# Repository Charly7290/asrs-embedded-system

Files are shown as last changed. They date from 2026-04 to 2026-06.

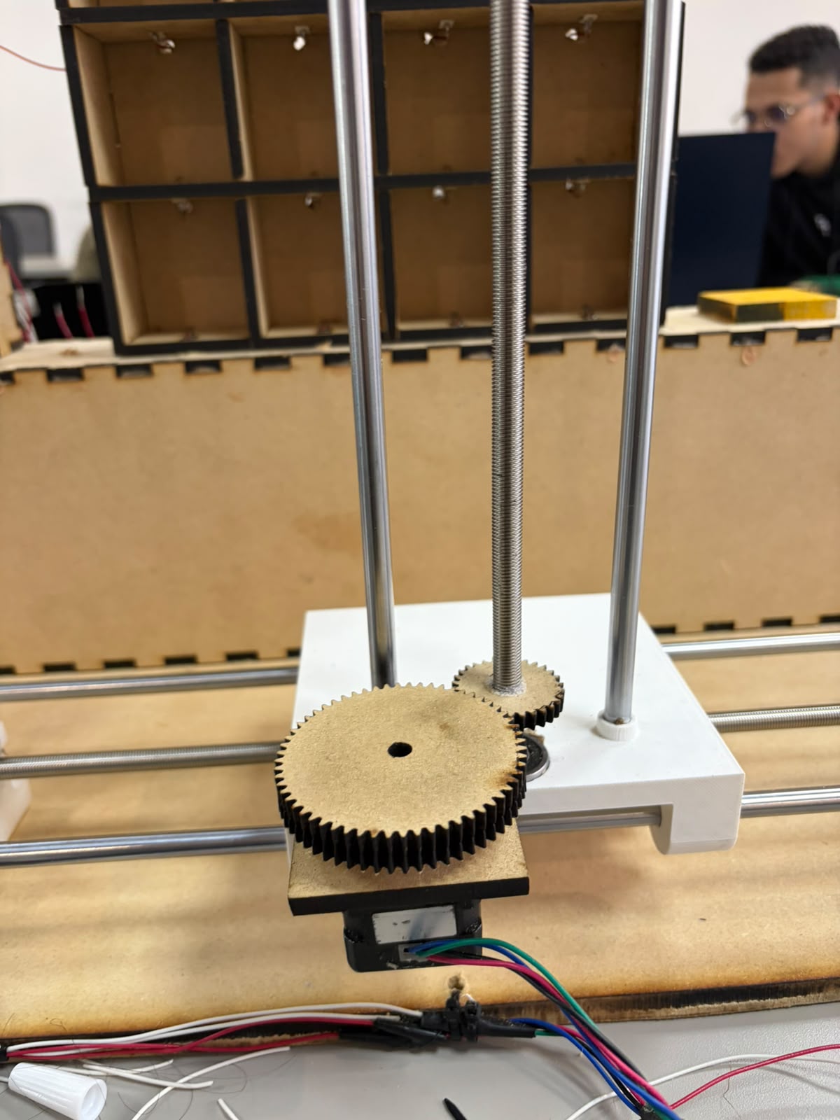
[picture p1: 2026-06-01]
hardware/photos/yshaft-transmission-system.jpeg

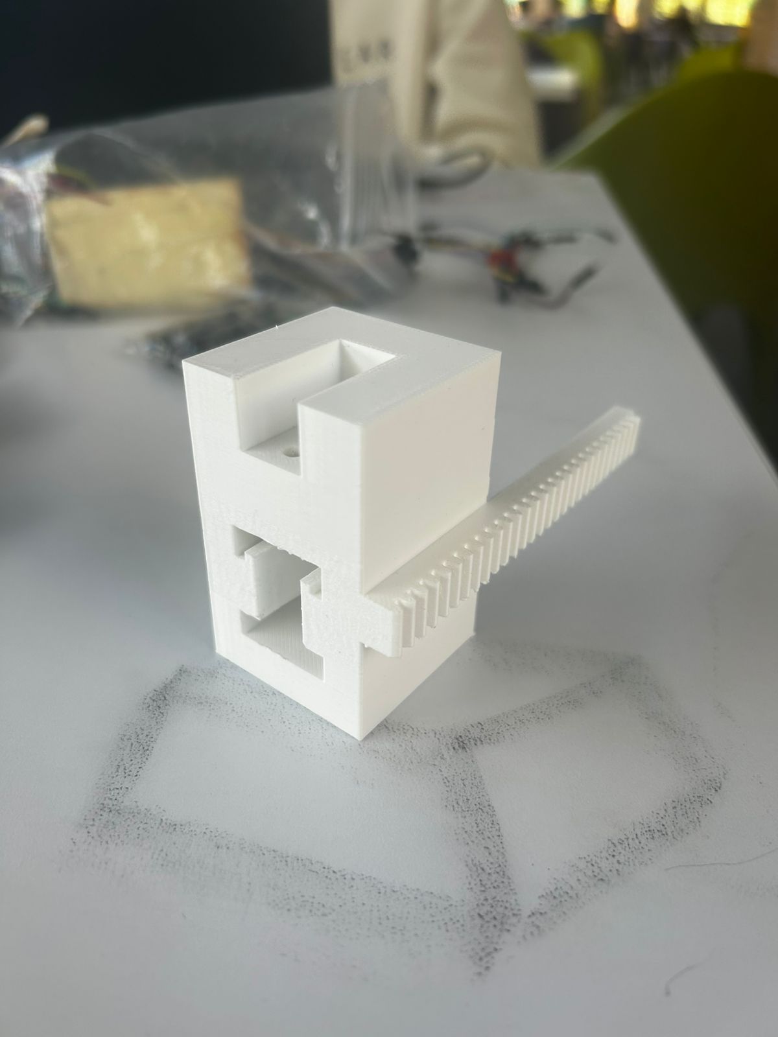
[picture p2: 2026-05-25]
hardware/photos/3dprint-end-effector.jpeg

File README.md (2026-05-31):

# AS/RS Embedded System

Prototipo de sistema embebido para un **Sistema Automatizado de Almacenamiento y Recuperación (AS/RS – Automated Storage and Retrieval System)** desarrollado como proyecto del curso de Sistemas Embebidos en la Universidad EIA.

> **Estado del proyecto:** Finalizado

---

## Estructura del repositorio

```
asrs-embedded/
├── docs/                    # Documentación del proyecto / Entregas
│   ├── firmware-design/     # Embedded Firmware Design Document
│   ├── test-cases/evidence/ # Evidencia de pruebas ejecutadas
│   └── images/              # Diagramas, fotos, capturas
├── firmware/                # Proyecto PlatformIO
│   ├── src/                 # Código fuente
│   │   ├── hal/             # Abstracción de hardware
│   │   ├── drivers/         # Drivers (stepper, l298n, mcp23017)
│   │   ├── services/        # Lógica de negocio (motion, inventory, logger)
│   │   └── app/             # Máquina de estados principal
│   ├── include/             # Headers globales (config, error codes)
│   ├── lib/                 # Librerías externas
│   └── test/                # Unit tests
├── hardware/                # Diseño electrónico
│   ├── schematic/           # Proyecto KiCad
│   ├── pcb/                 # Diseño de PCB 
│   ├── enclosure/           # Diseño CAD de la carcasa
│   └── photos/              # Fotos del ensamblaje
└── gui/                     # Interfaz gráfica de usuario
```

---

## Cómo compilar

### Requisitos

- [VS Code](https://code.visualstudio.com/) con la extensión [PlatformIO](https://platformio.org/)
- Cable USB para ESP32

### Pasos

```bash
git clone https://github.com/<usuario>/asrs-embedded.git
cd asrs-embedded
# Abrir con VS Code — PlatformIO detecta el proyecto automáticamente
# Compilar: Ctrl+Alt+B o botón ✓ en la barra de PlatformIO
# Subir al ESP32: Ctrl+Alt+U o botón →
# Monitor serial: Ctrl+Alt+S o botón 🔌
```

---

## Introducción

Los sistemas automatizados de almacenamiento y recuperación (AS/RS) son ampliamente utilizados en entornos industriales y logísticos para mejorar la eficiencia en la gestión de inventarios, reducir errores humanos y optimizar el uso del espacio de almacenamiento. Estos sistemas permiten almacenar, clasificar y recuperar productos mediante mecanismos automatizados controlados por sistemas electrónicos y de software.

En este proyecto se propone el diseño e implementación de un sistema embebido capaz de controlar un prototipo compacto de AS/RS, implementando sensado, actuación, protocolos de comunicación y una interfaz de usuario para gestionar las operaciones del sistema.

El sistema permitirá a un operario almacenar, recuperar e intercambiar productos dentro de diferentes compartimentos, manteniendo registro del estado del sistema y validando las operaciones mediante sensores y mediciones físicas.

El desarrollo del sistema seguirá buenas prácticas de ingeniería en hardware y firmware, incluyendo diseño arquitectónico, manejo de errores, trazabilidad de requisitos, validación mediante pruebas y documentación técnica formal.

---

## Descripción del Problema

En muchos entornos de almacenamiento de pequeña y mediana escala, como laboratorios, bodegas técnicas o entornos educativos, la gestión de inventarios se realiza de forma manual.

Este proceso presenta diversos problemas:

- Pérdida de tiempo en la búsqueda de productos.
- Errores humanos al ubicar o retirar elementos.
- Falta de control sobre la presencia o ausencia de productos en los compartimentos.
- Dificultad para mantener registros confiables del estado del sistema.

Los sistemas comerciales de AS/RS solucionan estos problemas, pero suelen tener alto costo y complejidad, lo que limita su implementación en entornos educativos o prototipos experimentales.

Por esta razón, este proyecto propone el desarrollo de un prototipo de sistema automatizado de almacenamiento y recuperación controlado por un sistema embebido, capaz de gestionar de forma automática el almacenamiento y recuperación de productos dentro de una estructura de compartimentos.

---

## Alcance del Proyecto

El proyecto contempla el desarrollo de un prototipo funcional de un sistema AS/RS compacto controlado por un sistema embebido, capaz de gestionar el almacenamiento y recuperación de productos.

El sistema incluirá los siguientes componentes:

- Un **mecanismo de posicionamiento** capaz de acceder a diferentes compartimentos de almacenamiento.
- **Sensores de presencia** para determinar si un compartimento contiene un producto.
- **Celdas de carga** para medir el peso del producto almacenado.
- **Actuadores controlados electrónicamente** para el movimiento del sistema.
- **Protocolos de comunicación** entre los módulos electrónicos (UART e I2C).
- Un **sistema de logging** que registre eventos, estados y errores del sistema.
- Una **interfaz gráfica de usuario (GUI)** que permita configurar parámetros, visualizar el estado del sistema y consultar errores o eventos relevantes.

La implementación física incluirá tarjeta electrónica ensamblada, fuente de alimentación externa, estructura mecánica funcional y carcasa de protección.

El proyecto se limita al desarrollo de un prototipo demostrativo a escala, orientado a validar la arquitectura y funcionamiento del sistema embebido.

---

## Objetivos

### Objetivo General

Diseñar e implementar un sistema embebido para el control de un sistema automatizado de almacenamiento y recuperación (AS/RS) que permita gestionar operaciones de almacenamiento, recuperación e intercambio de productos mediante sensores, actuadores y una interfaz de usuario.

### Objetivos Específicos

1. Diseñar la arquitectura de hardware y firmware del sistema embebido.
2. Implementar mecanismos de sensado de presencia y medición de peso en los compartimentos.
3. Desarrollar el control de actuadores para el posicionamiento del sistema.
4. Implementar un sistema de logging estructurado que registre eventos, estados y errores.
5. Integrar protocolos de comunicación entre módulos electrónicos (UART e I2C).
6. Diseñar e implementar una interfaz gráfica de usuario (GUI) para interacción con el sistema.
7. Implementar mecanismos robustos de manejo de errores y validación de sensores.
8. Realizar pruebas funcionales del sistema, asegurando la trazabilidad entre requisitos y pruebas.

---

## Equipo de Desarrollo

### Technical Lead — Carlos Daniel Murillo Mena
- Definir la arquitectura general del sistema.
- Aprobar decisiones técnicas del proyecto.
- Garantizar coherencia entre requisitos, diseño e implementación.
- Supervisar la integración y administrar el repositorio.

### Firmware Engineer — Owen Montiel Cardeñas
- Desarrollo de los módulos de firmware.
- Implementación del control de sensores y actuadores.
- Desarrollo del sistema de logging y protocolos de comunicación.
- Documentación del código fuente.

### Hardware Integration Engineer — Mateo Aldana Escobar
- Diseño del esquemático electrónico y PCB.
- Integración de sensores, actuadores y microcontrolador.
- Validación eléctrica del sistema.
- Ensamblaje físico y diseño de la carcasa.

### Verification & Testing Engineer — Michael Cuello Perez
- Definir el plan de pruebas del sistema.
- Construir y mantener la SRTM.
- Validar los requisitos mediante casos de prueba.
- Recolectar evidencia del funcionamiento del sistema.

---

## Entregas

| # | Entregable | Fecha | Estado |
|---|---|---|---|
| 1 | README + roles + problema | 11/03/2026 | ✅ |
| 2 | SRS + plan de testing + SRTM | 27/03/2026 | ✅ |
| 3 | Diagrama de bloques + esquemático + BOM | 17/04/2026 | ✅ |
| 4 | Entrega final + demo | 18–22/05/2026 | ✅ |

---

*Proyecto de Sistemas Embebidos — Universidad EIA — Periodo académico 2026-1*

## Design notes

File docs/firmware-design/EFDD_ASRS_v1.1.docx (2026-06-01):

EMBEDDED FIRMWARE DESIGN DOCUMENT

Sistema Automatizado de Almacenamiento y Recuperación (AS/RS)

Proyecto | AS/RS Embedded System
Curso | Sistemas Embebidos — 2026-1
Institución | Universidad EIA — Escuela de Ingeniería y Ciencias Básicas
Technical Lead | Carlos Daniel Murillo Mena
Firmware Engineer | Owen Montiel Cardeñas
HW Integration Engineer | Mateo Aldana Escobar
V&T Engineer | Michael Cuello Perez
Fecha | 2026-05-25
Versión | 1.2

# Control de versiones

Versión | Fecha | Autor | Cambios
1.0 | 2026-05-25 | Technical Lead | Versión inicial del EFDD.
1.1 | 2026-05-31 | Technical Lead | SRTM actualizada con TC-001 a TC-015 modulares por subsistema. Diagrama de estados rediseñado. Sección 12 actualizada para referenciar esquemático en repositorio.

# 1. Introducción

## 1.1 Descripción del sistema

El AS/RS (Automated Storage and Retrieval System) es un sistema embebido compacto que automatiza el almacenamiento y recuperación de productos en una estructura de 12 celdas organizadas en una matriz de 3 columnas por 4 filas. Un carro motorizado se desplaza en dos ejes — horizontal (X) y vertical (Y) — mediante motores NEMA17 controlados por módulos L298N, posicionándose en cualquiera de las 12 celdas para depositar o retirar productos a través de un extractor tipo servo.

El sistema es controlado por un ESP32-WROOM-32 que ejecuta firmware sobre FreeRTOS. Cada celda cuenta con un microswitch de presencia leído a través de un expansor I2C MCP23017. El peso del producto se mide mediante una celda de carga TAL221 con circuito de acondicionamiento analógico discreto. Una aplicación de escritorio en Python/tkinter se comunica con el ESP32 por UART para enviar comandos (STORE, RETRIEVE, SWAP) y visualizar el estado del inventario en tiempo real.

El proyecto fue desarrollado como prototipo educativo en el curso de Sistemas Embebidos de la Universidad EIA, periodo 2026-1, aplicando prácticas de ingeniería industrial: arquitectura en capas, máquina de estados, logging estructurado, trazabilidad de requisitos y verificación mediante casos de prueba.

## 1.2 Alcance del documento

Este documento especifica la arquitectura de hardware y firmware del sistema embebido. Define las decisiones de diseño, la estructura del firmware, los mecanismos de comunicación, la estrategia de logging, el manejo de errores y la trazabilidad con los requisitos del SRS.

El documento es el artefacto técnico central del proyecto y sirve como referencia para el desarrollo, la integración y la verificación del sistema.

# 2. Diagrama de bloques del sistema embebido

La figura 1 muestra la arquitectura de bloques del sistema embebido, incluyendo el microcontrolador central, los subsistemas de actuación y sensado, los bloques de comunicación y el circuito de seguridad.

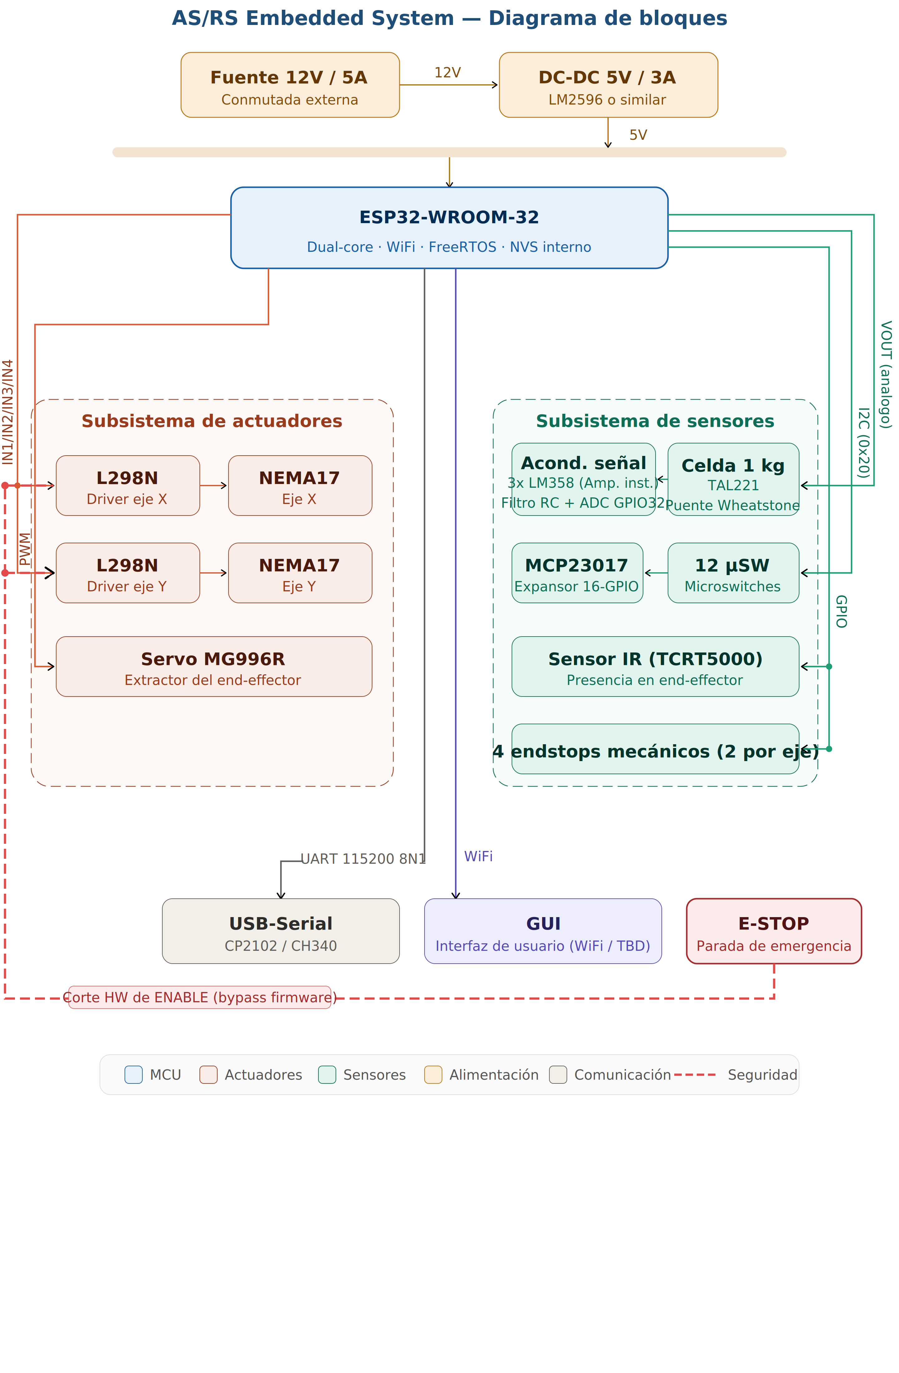
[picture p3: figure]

Figura 1. Diagrama de bloques del sistema AS/RS.

# 3. Arquitectura de firmware

## 3.1 Modelo arquitectónico

El firmware se organiza en cuatro capas horizontales. Cada capa solo interactúa con la capa inmediatamente inferior, garantizando bajo acoplamiento y alta cohesión. La implementación se realiza en C con módulos funcionales (archivos .c/.h), compilados con PlatformIO sobre el framework Arduino/ESP-IDF.

Capa | Módulos | Responsabilidad
Application | system.c — SystemController | Máquina de estados principal. Coordina todas las operaciones del sistema.
Services | motion.c, inventory.c, weight.c | Lógica de negocio: secuencias de movimiento, gestión de inventario, medición de peso.
Drivers | stepper.c, servo.c, mcp23017.c, load_cell.c, endstop.c, ir_sensor.c | Abstracción de hardware. Encapsula el acceso directo a periféricos.
HAL | gpio.c, i2c.c, adc.c, uart.c | Wrappers sobre ESP-IDF. Aíslan el resto del firmware de la API de bajo nivel.
Cross-cutting | logger.c, error_codes.h | Usados por todas las capas. Logger para UART, códigos de error estructurados.

## 3.2 Tareas FreeRTOS

El firmware ejecuta cinco tareas concurrentes sobre FreeRTOS. La comunicación entre tareas se realiza mediante colas (QueueHandle_t) y semáforos (SemaphoreHandle_t).

Tarea | Prioridad | Stack (words) | Responsabilidad
Task_SystemControl | 5 (más alta) | 4096 | Máquina de estados. Toma decisiones de sistema y despacha comandos.
Task_MotionControl | 4 | 4096 | Ejecuta secuencias de movimiento de steppers y servo.
Task_SensorRead | 3 | 2048 | Lee celda de carga, microswitches (MCP23017), sensor IR y endstops.
Task_Logger | 2 | 2048 | Consume la cola de log y envía por UART. Nunca bloquea otras tareas.
Task_GUIComm | 2 | 2048 | Recibe comandos de la GUI por UART y envía actualizaciones de estado.

# 4. Justificación de arquitectura

## 4.1 Lenguaje y toolchain

Se utiliza C con PlatformIO sobre Arduino/ESP-IDF. La elección de C sobre C++ se justifica por la disponibilidad inmediata de ejemplos y librerías para ESP32 en C, la facilidad de depuración y la reducción del tiempo de desarrollo dado el cronograma del proyecto. PlatformIO permite integración con Unity para pruebas unitarias.

## 4.2 Arquitectura en capas

La separación en capas garantiza que un cambio de hardware (por ejemplo, reemplazar el L298N por un DRV8825 en el futuro) solo requiere modificar la capa de drivers, sin afectar la lógica de servicios ni la máquina de estados. Esto reduce el riesgo de regresiones durante la integración.

## 4.3 Uso de FreeRTOS

FreeRTOS permite que el logging y la comunicación con la GUI operen de forma asíncrona sin bloquear el control de movimiento. La tarea de motion tiene prioridad más alta que el logger, garantizando que los tiempos de ciclo no se degraden por operaciones de I/O.

## 4.4 Módulos funcionales en lugar de POO

Se descartó POO con clases C++ para reducir el tiempo de diseño inicial. Los módulos funcionales con estructuras (struct) proveen encapsulamiento suficiente sin el overhead de vtables ni la complejidad de gestión de objetos en embedded. Cada módulo expone una API pública en su .h y mantiene su estado interno en variables estáticas del .c.

# 5. Diagrama de estados del firmware

La figura 2 muestra la máquina de estados del firmware con los 7 estados del sistema y todas sus transiciones.

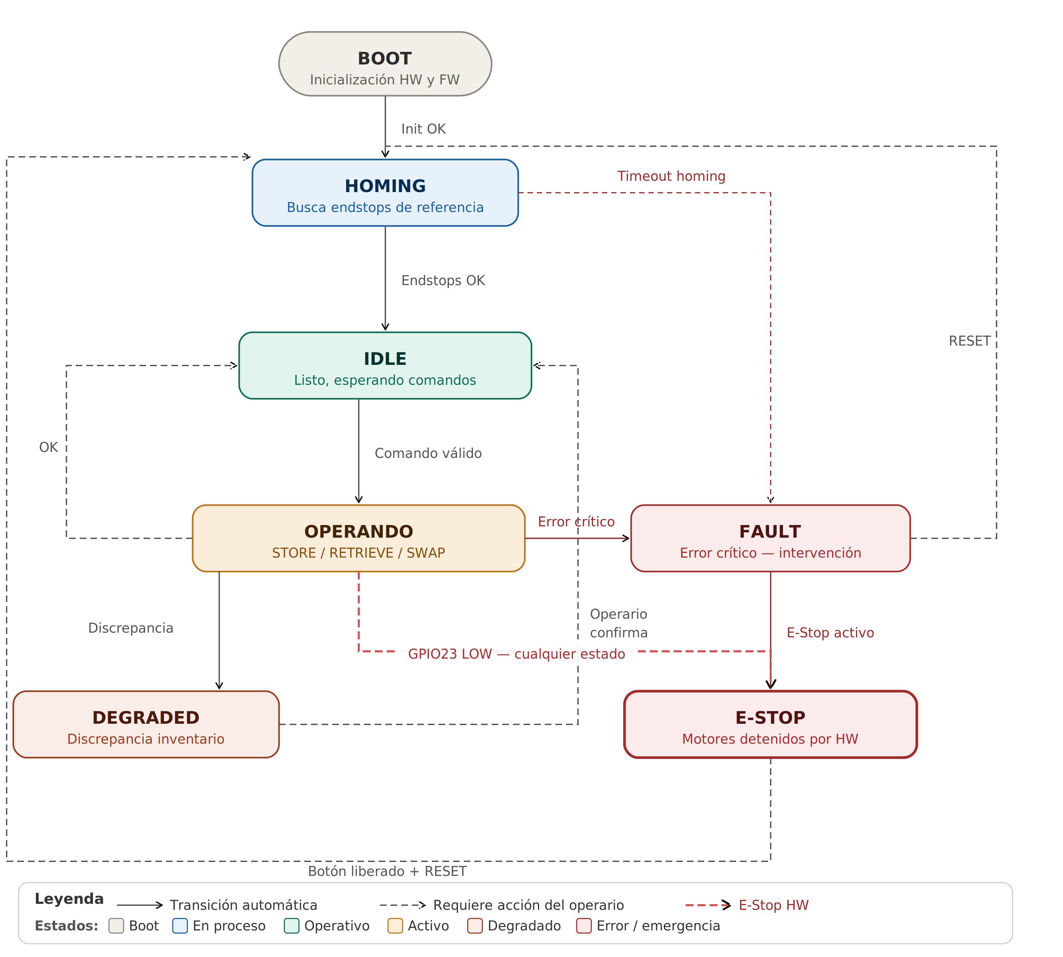
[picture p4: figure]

Figura 2. Diagrama de estados del firmware AS/RS.

## 5.1 Estados del sistema

Estado | Descripción
BOOT | Inicialización de hardware, HAL, drivers y FreeRTOS. Imprime versión de firmware en UART.
HOMING | Secuencia de homing: mueve ambos ejes hasta los endstops de referencia. Duración ≤30 s.
IDLE | Sistema listo. Espera comandos de la GUI. Actualiza estado de inventario periódicamente.
OPERANDO | Ejecutando una operación STORE, RETRIEVE o SWAP. No acepta nuevos comandos hasta completar.
DEGRADED | Discrepancia entre NVS y microswitches detectada. Sistema opera pero requiere confirmación del operario.
FAULT | Error crítico (sensor fuera de rango, timeout de movimiento). Requiere intervención del operario.
E-STOP | Botón de emergencia activo. Motores detenidos por hardware. Requiere reset y nuevo homing.

## 5.2 Transiciones

Desde | Hacia | Condición
BOOT | HOMING | Inicialización completa sin errores.
HOMING | IDLE | Ambos endstops de home alcanzados dentro del tiempo límite.
HOMING | FAULT | Timeout de homing (>30 s) o endstop no detectado.
IDLE | OPERANDO | Comando válido recibido de la GUI (STORE, RETRIEVE o SWAP).
OPERANDO | IDLE | Operación completada exitosamente.
OPERANDO | FAULT | ERR_WEIGHT_OUT_OF_RANGE, ERR_SENSOR_TIMEOUT, ERR_MOTION_TIMEOUT.
IDLE / OPERANDO | DEGRADED | Discrepancia entre NVS y estado real de microswitches en reconciliación.
DEGRADED | IDLE | Operario confirma reconciliación desde la GUI.
Cualquier estado | E-STOP | GPIO 23 cae a LOW (botón de emergencia presionado).
E-STOP | HOMING | Botón liberado + comando RESET desde GUI.
FAULT | HOMING | Comando RESET desde GUI.

# 6. Estrategia de manejo de errores

## 6.1 Códigos de error

Todos los errores siguen el patrón ERR_MÓDULO_CONDICIÓN. Se definen en error_codes.h como enumeraciones.

Código | Severidad | Acción del sistema
ERR_WEIGHT_OUT_OF_RANGE | ERROR | Detener operación, transición a FAULT, log ERROR.
ERR_WEIGHT_TIMEOUT | ERROR | Detener operación, transición a FAULT, log ERROR.
ERR_MOTION_TIMEOUT | ERROR | Deshabilitar motor, transición a FAULT, log ERROR.
ERR_SENSOR_TIMEOUT | ERROR | Transición a FAULT, log ERROR.
ERR_INVENTORY_DISCREPANCY | WARN | Transición a DEGRADED, log WARN, notificar GUI.
ERR_CELL_OCCUPIED | WARN | Rechazar operación STORE, log WARN.
ERR_CELL_EMPTY | WARN | Rechazar operación RETRIEVE, log WARN.
ERR_ESTOP_ACTIVE | ERROR | Transición a E-STOP, deshabilitar motores, log ERROR.
ERR_NOT_READY | WARN | Rechazar comando, log WARN.

## 6.2 Política de manejo

- Cada función de driver retorna un código de error (int). El valor 0 indica éxito.
- Las funciones de servicio verifican el retorno del driver y propagan el error hacia la capa superior.
- La tarea Task_SystemControl evalúa el error y decide la transición de estado correspondiente.
- Ningún error se ignora silenciosamente — todo error queda registrado en el log con nivel y código.
- Los errores WARN no detienen la operación en curso salvo indicación explícita.
- Los errores ERROR siempre detienen la operación y transicionan al estado FAULT o E-STOP.

# 7. Estructura de directorios y flujo de trabajo

## 7.1 Estructura del repositorio

asrs-embedded/

├── docs/ # Documentación del proyecto

│ ├── firmware-design/ # Embedded Firmware Design Document

│ ├── test-cases/

│ │ └── evidence/ # Evidencia de pruebas ejecutadas

│ └── images/ # Diagramas, fotos, capturas

├── firmware/ # Proyecto PlatformIO

│ ├── src/ # Código fuente

│ │ ├── hal/ # Abstracción de hardware

│ │ │ ├── gpio.c / gpio.h

│ │ │ ├── i2c.c / i2c.h

│ │ │ ├── adc.c / adc.h

│ │ │ └── uart.c / uart.h

│ │ ├── drivers/ # Drivers periféricos

│ │ │ ├── stepper.c / stepper.h

│ │ │ ├── servo.c / servo.h

│ │ │ ├── mcp23017.c / mcp23017.h

│ │ │ ├── load_cell.c / load_cell.h

│ │ │ ├── endstop.c / endstop.h

│ │ │ └── ir_sensor.c / ir_sensor.h

│ │ ├── services/ # Lógica de negocio

│ │ │ ├── motion.c / motion.h

│ │ │ ├── inventory.c / inventory.h

│ │ │ └── weight.c / weight.h

│ │ └── app/ # Máquina de estados principal

│ │ ├── system.c / system.h

│ │ └── gui_comm.c / gui_comm.h

│ ├── include/ # Headers globales (config, error_codes.h)

│ ├── lib/ # Librerías externas

│ ├── test/ # Unit tests Unity

│ └── platformio.ini

├── hardware/ # Diseño electrónico

│ ├── schematic/ # Proyecto KiCad (.kicad_sch)

│ ├── pcb/ # Imágenes PCB

│ ├── enclosure/ # Diseño CAD de la carcasa

│ └── photos/ # Fotos del ensamblaje

├── gui/ # App de escritorio Python/tkinter

│ ├── main.py

│ └── requirements.txt

└── README.md

## 7.2 Flujo de trabajo del repositorio

- Rama principal: main — solo código verificado y probado.
- Rama de desarrollo: develop — integración continua de features.
- Ramas de feature: feature/nombre — una por módulo o funcionalidad.
- Pull Request obligatorio para fusionar a develop. Revisado por el Technical Lead.
- Commits siguen convención: feat:, fix:, docs:, test:, refactor:.
- Cada entregable se etiqueta con tag semántico: v1.0, v1.1, etc.

# 8. Estrategia de logging

## 8.1 Formato de mensaje

Todos los mensajes de log siguen el formato estándar:

[timestamp_ms][LEVEL][MODULE][CODE] mensaje

Ejemplo: [001234][ERROR][WEIGHT][ERR_WEIGHT_OUT_OF_RANGE] peso=1050g > maximo=1000g

Ejemplo: [000012][INFO ][BOOT ][0] firmware=v1.0.0 commit=a3f9c12

Ejemplo: [005678][WARN ][INVEN ][ERR_INVENTORY_DISCREPANCY] celda=B2 esperado=OCUPADO actual=VACIO

## 8.2 Niveles de severidad

Nivel | Uso
INFO | Eventos normales del sistema: inicio, finalización de operaciones, cambios de estado.
WARN | Condiciones anómalas no críticas: discrepancias de inventario, celdas ocupadas al intentar STORE.
ERROR | Errores críticos que detienen la operación: sensor timeout, weight out of range, E-Stop activo.

## 8.3 Implementación

- El módulo logger.c mantiene una cola FreeRTOS de 32 entradas de tipo log_entry_t.
- Cualquier módulo puede llamar log_write(level, module, code, message) de forma thread-safe.
- Task_Logger consume la cola y envía por UART 115200 bps 8N1 sin bloquear otras tareas.
- El timestamp se obtiene de xTaskGetTickCount() convertido a ms.
- Al boot, el firmware imprime la línea INFO BOOT con versión semántica y hash del commit.

# 9. Gestión de comunicaciones

## 9.1 UART — Protocolo estándar #1

Parámetro | Valor
Velocidad | 115200 bps
Formato | 8N1 (8 bits datos, sin paridad, 1 bit de parada)
Hardware | USB-Serial CP2102 integrado en ESP32 DevKit V1
Pines | GPIO 1 (TX0) y GPIO 3 (RX0)
Usos | Logging de eventos (Task_Logger) y comunicación bidireccional con GUI (Task_GUIComm)
Justificación | Canal único para logging y GUI simplifica el hardware y reduce el número de puertos serie requeridos.

Protocolo GUI — comandos y respuestas

La GUI envía comandos ASCII terminados en \n. El ESP32 responde con JSON.

Comando STORE: STORE:A1\n

Comando RETRIEVE: RETRIEVE:B3\n

Comando SWAP: SWAP:A1:C4\n

Comando RESET: RESET\n

Respuesta OK: {"status":"OK","op":"STORE","celda":"A1","peso":245.3}

Respuesta ERR: {"status":"ERROR","code":"ERR_CELL_OCCUPIED","celda":"A1"}

Evento estado: {"event":"STATE","state":"IDLE","inventory":{"A1":245,"B3":0,...}}

## 9.2 I2C — Protocolo estándar #2

Parámetro | Valor
Velocidad | 100 kHz (modo estándar)
Pines | GPIO 21 (SDA) y GPIO 22 (SCL)
Dispositivo | MCP23017 — expansor de 16 GPIO para microswitches
Dirección | 0x20 (A0=A1=A2=GND)
Pull-ups | 4.7 kΩ a 3.3V en SDA y SCL (integrados en módulo breakout)
Interrupción | INTA del MCP23017 → GPIO 4 ESP32. Activa baja. Evita polling continuo.
Justificación | I2C permite leer 12 microswitches con solo 2 pines del ESP32. La interrupción INTA garantiza detección inmediata sin polling.

# 10. Descripción del funcionamiento del sistema

## 10.1 Arranque y homing

Al energizar el sistema, el firmware ejecuta la secuencia de boot: inicializa el HAL, configura los drivers de periféricos, imprime la versión en UART y lanza las tareas FreeRTOS. Inmediatamente entra al estado HOMING, en el que mueve ambos ejes hacia sus endstops de referencia (home). Una vez alcanzados los dos endstops, el sistema registra la posición (0,0) como origen y transiciona a IDLE.

Paralelamente, en HOMING se realiza la reconciliación de inventario: se lee el estado real de los 12 microswitches vía MCP23017 y se compara contra el último estado persistido en NVS. Si hay discrepancias, el sistema entra a DEGRADED e informa al operario por la GUI. Si no hay discrepancias, continúa en IDLE.

## 10.2 Operación STORE

El operario envía el comando STORE:XN desde la GUI, donde X es la columna (A, B o C) y N es la fila (1 a 4). El firmware verifica que la celda destino esté vacía consultando el microswitch correspondiente. Si está ocupada, responde con ERR_CELL_OCCUPIED y permanece en IDLE.

Si la celda está vacía, el sistema transiciona a OPERANDO y ejecuta la secuencia: (1) mueve el carro a la posición de la celda usando los motores stepper, (2) activa el servo para extender el end-effector, (3) lee el peso con la celda de carga y lo valida contra el rango 10–1000 g, (4) retrae el servo, (5) actualiza el NVS con el estado de la celda y el peso medido. Al finalizar, responde a la GUI con OK y el peso registrado, y transiciona a IDLE.

## 10.3 Operación RETRIEVE

El operario envía RETRIEVE:XN. El firmware verifica que la celda tenga producto (microswitch activo y peso en NVS > 5 g). Si está vacía, responde ERR_CELL_EMPTY. Si tiene producto, ejecuta: (1) movimiento a la celda, (2) extensión del servo para recoger el producto, (3) verificación de peso en el end-effector (debe coincidir ±15 g con el peso registrado en NVS), (4) retracción del servo, (5) actualización de NVS marcando la celda como vacía. Responde con OK a la GUI.

## 10.4 Operación SWAP

El operario envía SWAP:X1N1:X2N2. El firmware ejecuta dos operaciones secuenciales usando el end-effector como buffer: primero un RETRIEVE de la celda origen, luego un STORE en la celda destino con el producto recuperado, y finalmente un STORE en la celda origen con el producto que estaba en destino. Si cualquier paso falla, el sistema entra a FAULT con el estado del swap registrado en NVS para posible recuperación.

## 10.5 Detención de emergencia

El botón E-Stop corta directamente los pines ENA y ENB de ambos módulos L298N por hardware, deteniendo los motores en menos de 200 ms sin intervención del firmware. La caída del GPIO 23 (pull-down a GND) genera una interrupción en el ESP32 que transiciona el sistema a E-STOP, registra el evento en el log con nivel ERROR y notifica a la GUI. Los motores permanecen deshabilitados hasta que el operario libere el botón y envíe el comando RESET.

# 11. Descripción de módulos de firmware

## 11.1 Capa HAL

Módulo | Descripción y API principal
gpio.c | Wrapper sobre GPIO de ESP-IDF. Configura pines como entrada/salida y lee/escribe niveles lógicos. gpio_init(), gpio_write(), gpio_read().
i2c.c | Inicializa el bus I2C en GPIO 21/22 a 100 kHz. Provee i2c_write_reg() e i2c_read_reg() para comunicación con MCP23017.
adc.c | Configura ADC1 del ESP32 en GPIO 32 con atenuación 11 dB (rango 0–3.3 V). Provee adc_read_mv() que retorna el valor en mV promediado sobre N muestras.
uart.c | Configura UART0 a 115200 bps 8N1. Provee uart_send_string() y uart_read_line() con timeout. Usado por logger.c y gui_comm.c.

## 11.2 Capa Drivers

Módulo | Descripción y API principal
stepper.c | Controla los módulos L298N para los motores NEMA17. Implementa la secuencia de paso completo y medio paso. stepper_init(), stepper_move_steps(motor, steps, dir), stepper_stop(motor).
servo.c | Genera señal PWM a 50 Hz sobre GPIO 13 para el servo MG996R. servo_init(), servo_set_angle(degrees) con rango 0–180°.
mcp23017.c | Driver I2C para el expansor MCP23017. Configura puertos A y B como entradas con pull-ups. Configura INTA como interrupción. mcp_init(), mcp_read_all() retorna uint16_t con estado de 16 pines.
load_cell.c | Acondicionamiento del ADC para la celda de carga. Aplica tara, calibración y promedio de 16 muestras. load_cell_tare(), load_cell_read_grams() retorna float.
endstop.c | Lectura de los 4 endstops mecánicos con debounce por software. endstop_init(), endstop_triggered(axis, type) retorna bool.
ir_sensor.c | Lectura del sensor TCRT5000 en GPIO 33. ir_sensor_init(), ir_sensor_detected() retorna bool.

## 11.3 Capa Services

Módulo | Descripción y API principal
motion.c | Lógica de movimiento de alto nivel. Calcula los pasos necesarios para llegar a una celda dada la topología 3×4 y el tornillo T8 (paso 8 mm). motion_home(), motion_goto_cell(col, row), motion_get_position().
inventory.c | Gestión del estado del inventario. Lee microswitches, actualiza NVS, reconcilia discrepancias. inventory_init(), inventory_get_cell(col, row), inventory_set_cell(col, row, weight), inventory_reconcile().
weight.c | Validación de peso con lógica de negocio. Llama a load_cell_read_grams(), verifica rango 10–1000 g, genera error si fuera de rango. weight_measure_and_validate() retorna error_t.

## 11.4 Capa Application

Módulo | Descripción y API principal
system.c | Máquina de estados principal. Gestiona las transiciones entre BOOT, HOMING, IDLE, OPERANDO, DEGRADED, FAULT y E-STOP. Despacha operaciones STORE, RETRIEVE y SWAP a los servicios correspondientes. system_init(), system_run() (loop principal de la tarea Task_SystemControl).
gui_comm.c | Protocolo de comunicación con la GUI. Parsea comandos ASCII recibidos por UART (STORE, RETRIEVE, SWAP, RESET) y serializa respuestas en JSON. gui_comm_init(), gui_comm_process_rx(), gui_comm_send_state().

## 11.5 Módulos transversales (Cross-cutting)

Módulo | Descripción y API principal
logger.c | Sistema de logging asíncrono. Mantiene una cola FreeRTOS de 32 entradas. log_write(level, module, code, msg) es thread-safe. Task_Logger consume la cola y envía por UART con formato [ts][LEVEL][MODULE][CODE] msg.
error_codes.h | Define la enumeración error_t con todos los códigos ERR_MÓDULO_CONDICIÓN del sistema. Incluido por todos los módulos. No contiene lógica, solo definiciones.

# 12. Esquemático electrónico

El esquematico electronico completo del sistema se encuentra en el repositorio GitHub del proyecto, en el directorio hardware/schematic/. Se incluyen el archivo fuente KiCad (.kicad_sch) y la exportacion en PDF.

13. Matriz de trazabilidad de requisitos (SRTM)

La SRTM completa se encuentra en el documento SRS_AS-RS_v1.4.docx, sección 5. A continuación se presenta un resumen de la trazabilidad entre los requisitos principales y los módulos de firmware que los implementan.

Req. ID | Requisito | Modulo firmware | Test Case
RF-01 | Homing al boot | motion.c, system.c | TC-001
RF-02 | Posicionamiento eje X | motion.c, stepper.c | TC-002
RF-02 | Posicionamiento eje Y | motion.c, stepper.c | TC-003
RF-10 | Parada de emergencia E-Stop | system.c (ISR GPIO 23) | TC-004
RF-07 | Sensor IR TCRT5000 | ir_sensor.c, inventory.c | TC-005
RF-06 | Medicion de peso AD623 | weight.c, load_cell.c | TC-006
RF-07, RF-09 | MCP23017 + microswitches | mcp23017.c, inventory.c | TC-007
RF-12 | Luces piloto + reles | gpio.c, system.c | TC-008
RF-13 | Interfaz GUI | gui_comm.c, system.c | TC-009
RF-12 | Logging estructurado UART | logger.c | TC-010
RNF-02 | Alimentacion externa | (hardware) | TC-011
RNF-04 | Protocolos UART e I2C | uart.c, i2c.c | TC-012
RNF-03 | Implementacion fisica PCB | (hardware) | TC-013
RNF-05 | Versionado firmware | main.cpp (boot log) | TC-014
RF-03,RF-04,RF-05 | Operaciones STORE/RETRIEVE/SWAP | system.c, inventory.c, motion.c | TC-015

Embedded Firmware Design Document | 2026-1

Universidad EIA | Sistemas Embebidos | AS/RS Embedded System

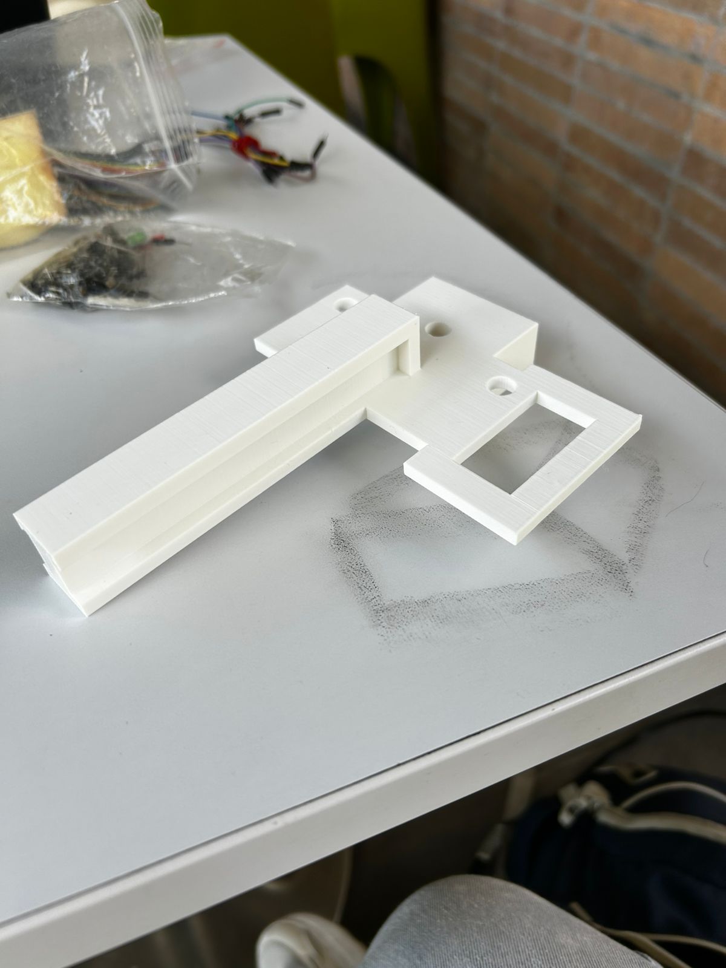
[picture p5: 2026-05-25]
hardware/photos/3dprint-carriage-y.jpeg

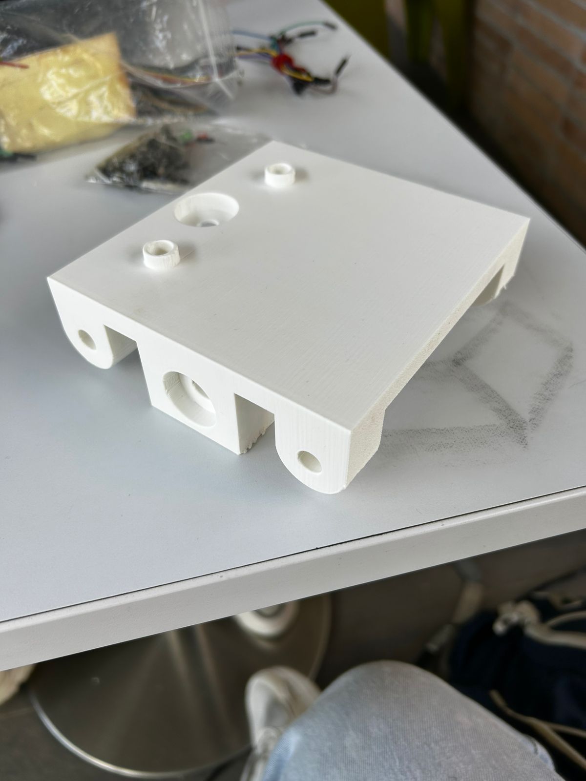
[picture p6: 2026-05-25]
hardware/photos/3dprint-carriage-x.jpeg

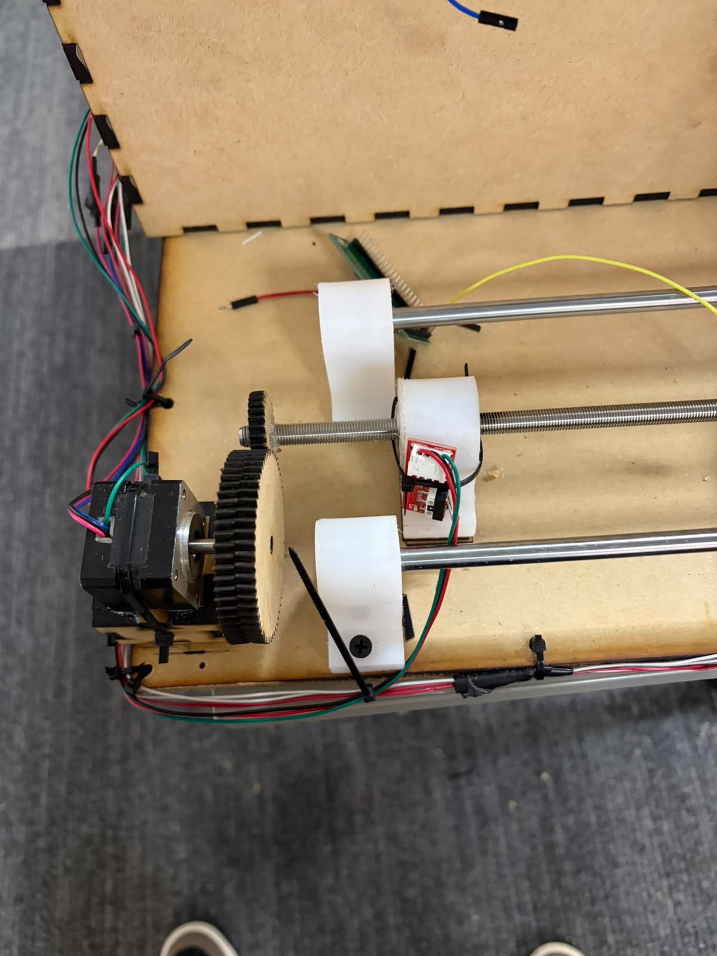
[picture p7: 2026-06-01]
hardware/photos/Xshaft-transmission-system.jpeg

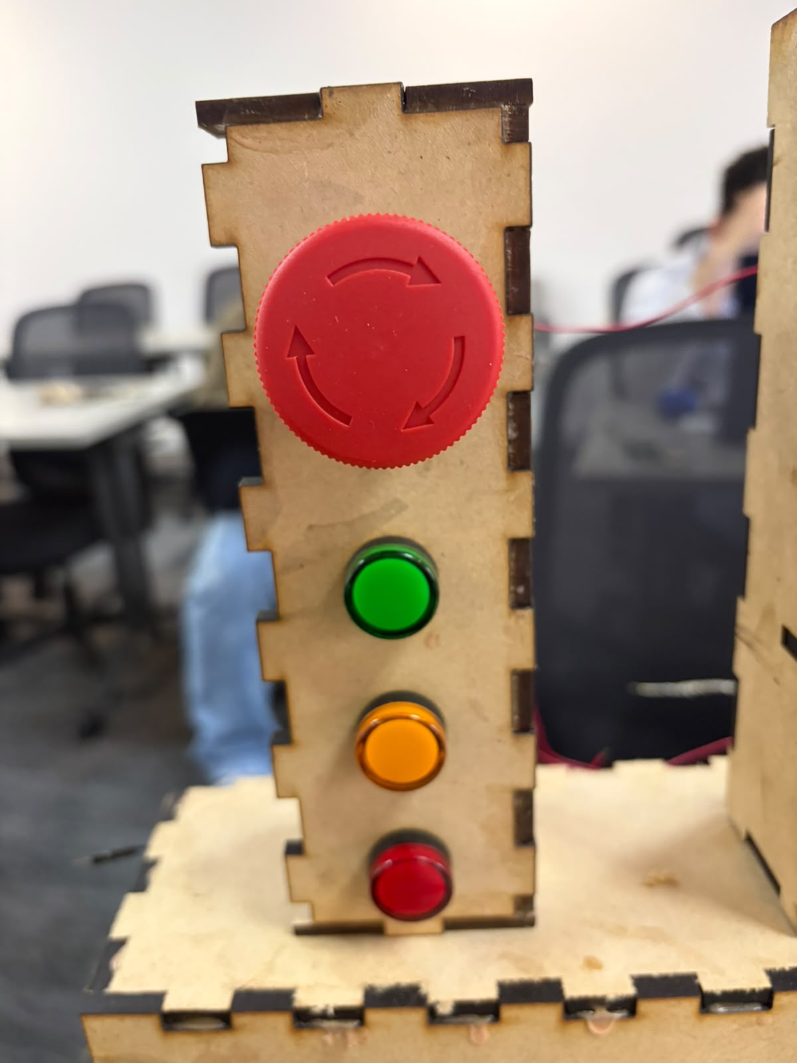
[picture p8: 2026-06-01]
hardware/photos/indicator-lights-and-emergency-stop-mounting.jpeg

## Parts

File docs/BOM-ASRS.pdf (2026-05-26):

# | Categoría | Componente | Referencia / Modelo | Cant. | Trazabilidad | Notas

1 | MCU y comunicación | ESP32 DevKit V1 | ESP32-WROOM-32 + CP2102 integrado | 1 | RF-01 a RF-13, RNF-04, RNF-05 | Incluye USB-Serial integrado.
2 | | Capacitor bypass | 100 nF cerámico | 2 | RNF-02 | Bypass de alimentación del ESP32.
3 | Actuadores y drivers | Stepper NEMA17 — eje Y | 17HS3401, 1.3 A, 26 N·cm | 1 | RF-01, RF-02 | Eje Y (vertical).
4 | | Stepper NEMA17 — eje X | 17HS2408, 0.6 A, 16 N·cm | 1 | RF-01, RF-02 | Eje X (horizontal).
5 | | Módulo driver L298N | Módulo rojo con IC L298N integrado y disipador | 2 | RF-01, RF-02, RF-10 | Uno por eje. Quitar jumpers ENA y ENB para E-Stop.
6 | | Servo MG996R | Metal gear, ~10 kg·cm | 1 | RF-03, RF-04, RF-05 | Extractor del end-effector. PWM 50 Hz.
7 | | Capacitor electrolítico 100 µF | 100 µF 25V (uno por módulo L298N) | 2 | RNF-02 | Uno por módulo L298N. Entre pin 12V y GND.
8 | Sensores | Celda de carga 1 kg | TAL221 o YZC-131 (tipo barra) | 1 | RF-06, RF-07 | Rango 10–1000 g. Montada en el end-effector.
9 | | Op-amp LM358N | Dual op-amp, DIP-8, single supply 3–32V | 3 | RF-06, RF-07 | IC1: buffers, IC2: diferenciador + filtro, IC3: amp. final.
10 | | Resistencia Rg | 1 kΩ · 1% · 1/4W | 1 | RF-06 | Ganancia G₁=21×.
11 | | Resistencias red OA3 | 10 kΩ · 1% · 1/4W | 4 | RF-06, RF-07 | Red resistiva OA3. Usar 1% mismo lote.
12 | | Resistencias divisor Vref | 10 kΩ · 5% · 1/4W | 2 | RF-06 | Divisor Vref=2.5V.
13 | | Resistencias filtro Sallen-Key | 160 kΩ · 5% · 1/4W | 2 | RF-06 | Filtro Sallen-Key, fc≈10 Hz.
14 | | Resistencia Rin amp. final | 10 kΩ · 1% · 1/4W | 1 | RF-06 | Entrada OA5, G₃=5.7×.
15 | | Resistencia Rf amp. final | 47 kΩ · 1% · 1/4W | 1 | RF-06 | Retroalimentación OA5.
16 | | Capacitores 100 nF C0G | 100 nF · C0G · 25V | 8 | RF-06 | Bypass VCC (×3), Vref (×1), filtro Sallen-Key (×2), reserva (×2).
17 | | Expansor I/O MCP23017 | DIP-28 o módulo breakout | 1 | RF-03, RF-04, RF-07, RF-09, RNF-04 | I2C addr 0x20. 12 GPIO para microswitches. Pull-ups 4.7kΩ en SDA/SCL si es DIP.
18 | | Microswitch mini | KW12-3 o similar, 3 pines | 12 | RF-03, RF-04, RF-07, RF-09 | Uno por celda (3×4=12). NC a GND, COM al MCP23017.
19 | | Sensor IR TCRT5000 | Módulo reflectivo con comparador | 1 | RF-07 | Presencia en end-effector.
20 | | Endstop mecánico con PCB | Microswitch + PCB + conector | 4 | RF-01, RF-11 | 2 por eje: homing y límite.

Universidad EIA · Sistemas Embebidos 2026-1 · Componentes electrónicos

## Bill of Materials (BOM) — AS/RS Embedded System

21 | Alimentación | Fuente conmutada 12V 5A | 60W, conector barrel jack | 1 | RNF-02 | Alimenta DRV8825 y módulo DC-DC.
22 | | Módulo DC-DC LM2596 | Buck ajustable, 12V → 5V, 3A | 1 | RNF-02 | Genera riel 5V. Ajustar a 5.0V antes de conectar cargas.
23 | | Transformador 24V AC | 220V AC → 24V AC, 5VA mínimo | 1 | RNF-02 | Alimentación 24V AC para luces piloto.
24 | | Conector barrel jack hembra | 5.5×2.1 mm, panel mount | 1 | RNF-02 | Entrada de alimentación 12V.
25 | | Capacitor electrolítico 470 µF | 470 µF 16V electrolítico | 1 | RNF-02 | Bulk en salida del LM2596. Estabiliza el riel 5V.
26 | | Capacitor electrolítico 1000 µF | 1000 µF 16V electrolítico | 1 | RNF-02 | Cerca del servo. Absorbe picos de corriente al arrancar.
27 | Seguridad | Botón E-Stop tipo hongo | NC (normalmente cerrado), rojo | 1 | RF-10 | Corta ENA/ENB de los L298N por hardware.
28 | | Resistencia pull-down E-Stop | 10 kΩ · 5% · 1/4W | 1 | RF-10 | Entre GPIO 23 ESP32 y GND. Garantiza lectura LOW al abrir el E-Stop.
29 | Indicadores | Luz piloto 24V AC/DC | Verde · Amarilla · Roja — panel mount | 3 | RF-12 | Verde: operativo, amarillo: advertencia, rojo: error.
30 | | Relé 5V | 5V bobina, contacto 250V AC 10A | 3 | RF-12 | Uno por luz piloto. Controlado por BC547.
31 | | Transistor BC547 | NPN, TO-92 | 3 | RF-12 | Driver del relé desde GPIO ESP32.
32 | | Diodo 1N4007 | Rectificador, 1A 1000V | 3 | RF-12 | Protección flyback en la bobina del relé.
33 | | Resistencia base transistor | 1 kΩ · 5% · 1/4W | 3 | RF-12 | Limitadora de base del BC547.
34 Tarjeta y componentes | pasivos | Tarjeta universal perforada | 9×15 cm, doble cara | 2 | RNF-03 | Tarjeta principal y auxiliar.
35 | | Tarjeta perforada pequeña | 3×5 cm, doble cara | 1 | RF-06 | Preamp en el end-effector.
36 | | Estaño 60/40 | 0.8 mm, rollo | 1 | RNF-03 | Soldadura.

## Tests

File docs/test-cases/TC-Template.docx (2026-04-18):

TEST CASE | ☐ Passed ☐ Failed ☐ Blocked

TC - XXX
Requirement Traceability
Test Type
Test Objective
Firmware Version
Hardware Setup
Preconditions
Test Procedure
Expected Results | Actual Results

Evidence
Executed by: Date: | Reviewed by (TL): Date:

Test Case Template | Página de

Universidad EIA | Sistemas Embebidos | AS/RS Embedded System

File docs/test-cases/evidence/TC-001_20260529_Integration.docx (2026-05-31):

TEST CASE | ☐ Passed x Failed ☐ Blocked

TC-001
Requirement Traceability | RF-01
Test Type (Unit / Driver / Integration / HIL / System) | Integration
Test Objective | Permitir la inicialización del sistema y dejar todo en un estado listo para la ejecución de la secuencia

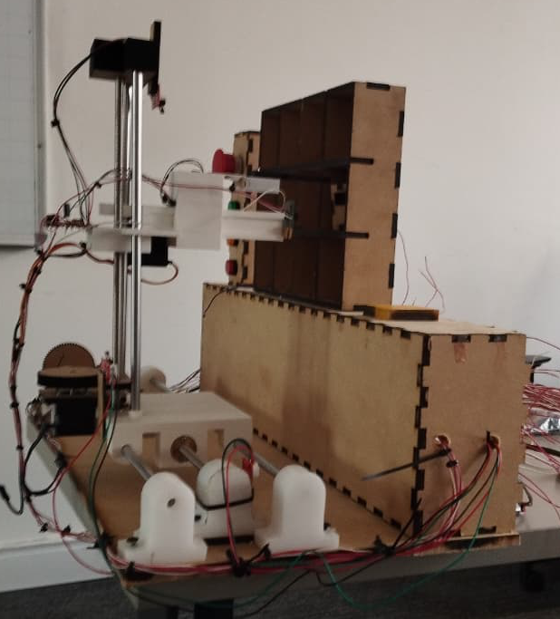
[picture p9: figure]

Hardware Setup
Preconditions | - Elementos físicos - Finales de carreras - Mecanismo de movimiento
Test Procedure (numbered steps) | 1. Se realizaron las piezas de todo el mecanismo 2. Se acondicionaron los finales de carrera 3. Se realizo el código
Expected Results | Actual Results
Al tener todos los elementos físicos y finales de carrera era necesario que las plataformas llegaran a la posición inicial de todo junto con el código | No se logro lo esperado, debido a problemas con la programación de los GPIO

Evidence
Executed by / Date | Reviewed by (TL) / Date
Michael Cuello, Owen Montiel | Carlos Murillo

Universidad EIA | Sistemas Embebidos | AS/RS Embedded System

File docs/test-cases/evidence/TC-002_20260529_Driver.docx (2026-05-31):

TEST CASE | X Passed ☐ Failed ☐ Blocked

TC-002
Requirement Traceability | RF-02
Test Type (Unit / Driver / Integration / HIL / System) | Driver
Test Objective | Probar el posicionamiento del eje x realizado por motores paso a paso y relación de engranajes

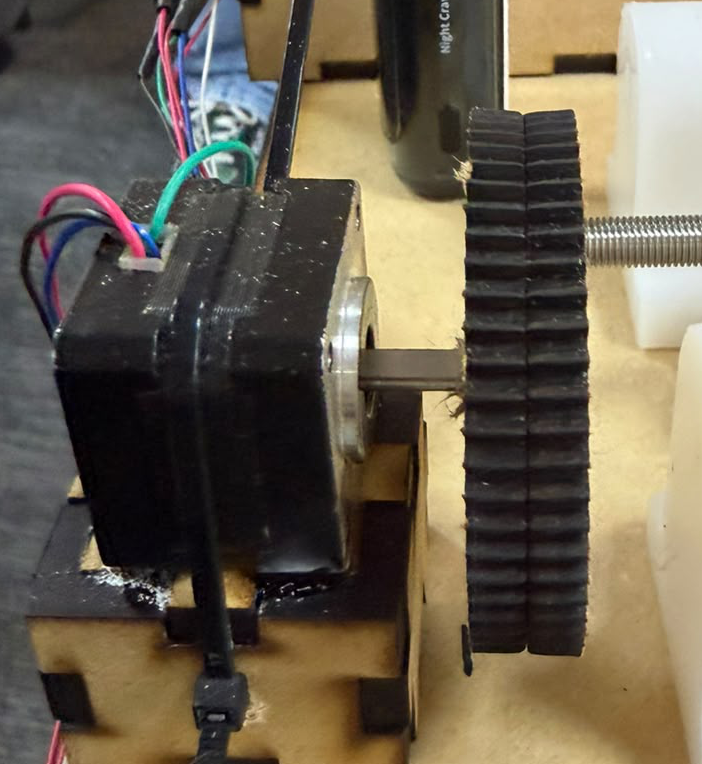
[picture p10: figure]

Hardware Setup
Preconditions | - Funcionamiento correcto de los motores paso a paso - Relación de engranajes conectadas al eje - Fuente externa y puente H
Test Procedure (numbered steps) | 1. Se realizo la transmisión de engranjes 2. Se hizo el respectivo acople al eje 3. Se conectó el motor a la transmisión
Expected Results | Actual Results
Al realizar la prueba se esperaba ver el correcto funcionamiento de la transmisión de engranajes y el movimiento de la plataforma inferior | Se logró observar el correcto funcionamiento de la plataforma y el movimiento adecuado y necesario

Evidence

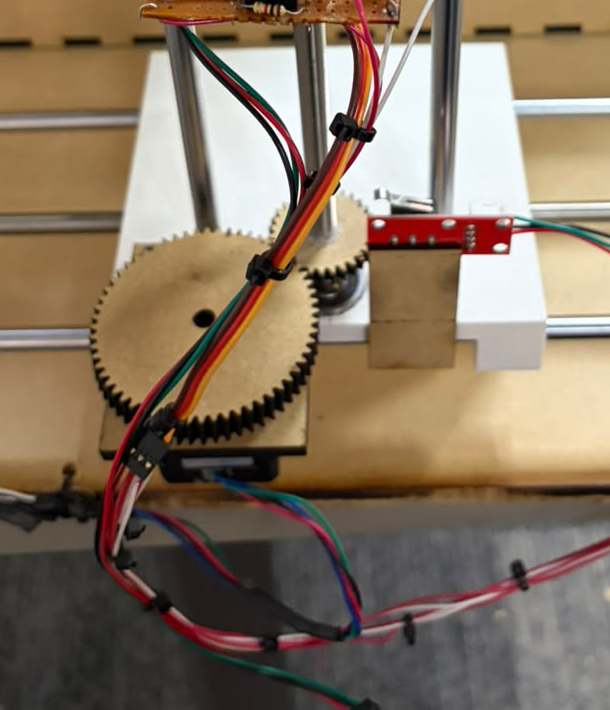
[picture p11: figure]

Executed by / Date | Reviewed by (TL) / Date
Michael Cuello, Mateo Aldana | Carlos Murillo

Universidad EIA | Sistemas Embebidos | AS/RS Embedded System

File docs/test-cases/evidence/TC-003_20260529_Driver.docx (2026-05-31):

TEST CASE | X Passed ☐ Failed ☐ Blocked

TC-003
Requirement Traceability | RF-02
Test Type (Unit / Driver / Integration / HIL / System) | Driver
Test Objective | Probar el posicionamiento del eje y realizado por motores paso a paso y relación de engranajes

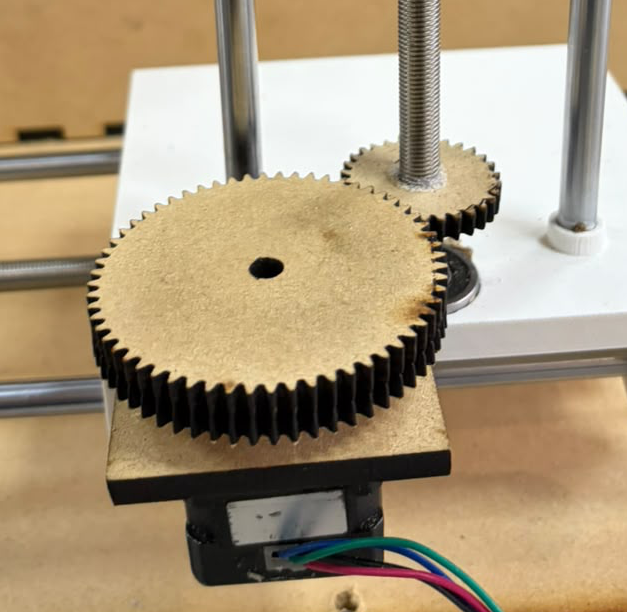
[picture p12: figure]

Hardware Setup
Preconditions | - Funcionamiento correcto de los motores paso a paso - Relación de engranajes conectadas al eje - Fuente externa y puente H
Test Procedure (numbered steps) | 1. Se realizo la transmisión de engranjes 2. Se hizo el respectivo acople al eje 3. Se conectó el motor a la transmisión
Expected Results | Actual Results
Al realizar la prueba se esperaba ver el correcto funcionamiento de la transmisión de engranajes y el movimiento de la plataforma superior | Se logró observar el correcto funcionamiento de la plataforma y el movimiento adecuado y necesario

Evidence

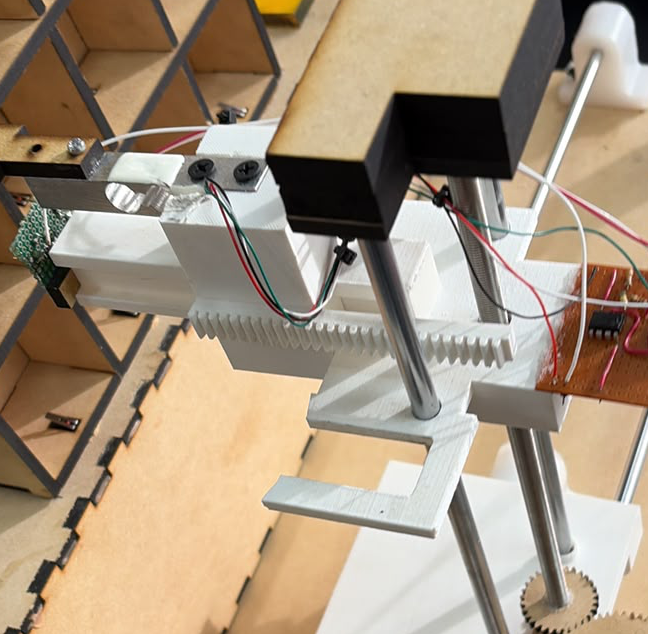
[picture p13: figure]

Executed by / Date | Reviewed by (TL) / Date
Michael Cuello, Mateo Aldana | Carlos Murillo

Universidad EIA | Sistemas Embebidos | AS/RS Embedded System

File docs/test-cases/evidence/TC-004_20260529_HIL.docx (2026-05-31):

TEST CASE | X Passed ☐Failed ☐ Blocked

TC-004
Requirement Traceability | RF-10
Test Type (Unit / Driver / Integration / HIL / System) | HIL
Test Objective | Probar el parado de emergencia del botón STOP, donde todos los motores se frenaran

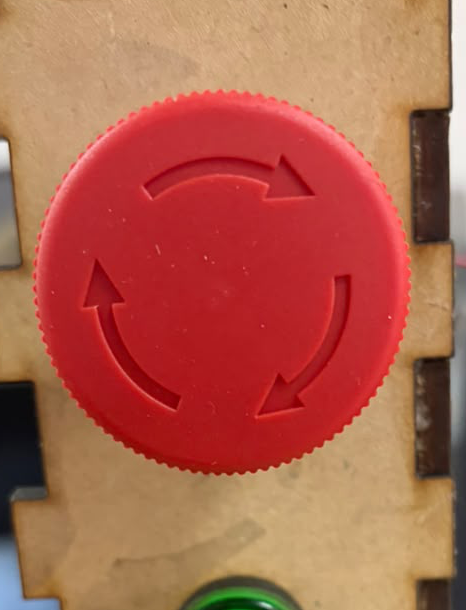
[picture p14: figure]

Hardware Setup
Preconditions | - Botón parado de emergencia - Conexiones puente H
Test Procedure (numbered steps) | 1. Se realizaron las respectivas conexiones al puente H con las entradas al botón de emrgencia
Expected Results | Actual Results
Al presionar el botón de emergencia todo el sistema de motores se debe detener | Se logró con lo esperado el botón de emergencia detuvo el sistema de motores

Evidence
Executed by / Date | Reviewed by (TL) / Date
Michael Cuello, Mateo Aldana, Carlos Murillo | Carlos Murillo

Universidad EIA | Sistemas Embebidos | AS/RS Embedded System

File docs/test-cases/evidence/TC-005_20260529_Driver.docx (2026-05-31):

TEST CASE | X Passed ☐Failed ☐ Blocked

TC-005
Requirement Traceability | RF-07
Test Type (Unit / Driver / Integration / HIL / System) | Driver
Test Objective | Ver correcto funcionamiento del sensor IR para la detección de cajas.

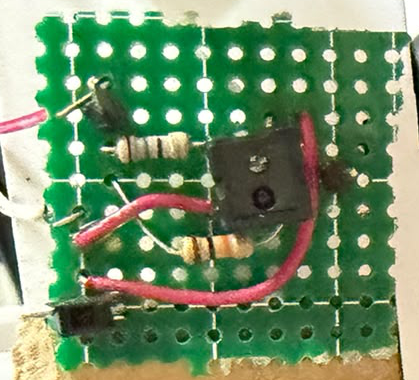
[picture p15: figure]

Hardware Setup
Preconditions | - Circuito de acondicionamiento del senro IR
Test Procedure (numbered steps) | 1. Se realizo el esquemático del circuito 2. Se conectaron los componentes 3. Se soldaron
Expected Results | Actual Results
Al acercar un objeto al sensor IR este debe mostrar y entregar voltaje al multímetro y ESP32 | Luego de acercar nuestra caja al sensor IR se obtuvo el resultado esperado de voltaje.

Evidence
Executed by / Date | Reviewed by (TL) / Date
Michael Cuello, Mateo Aldana, Carlos Murillo | Carlos Murillo

Universidad EIA | Sistemas Embebidos | AS/RS Embedded System

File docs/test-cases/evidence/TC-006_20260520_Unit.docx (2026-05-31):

TEST CASE | x Passed ☐ Failed ☐ Blocked

TC-006
Requirement Traceability | RF_06
Test Type (Unit / Driver / Integration / HIL / System) | Unit
Test Objective | Verificar el rango de la capacidad de carga de nuestra celda 200-1000g

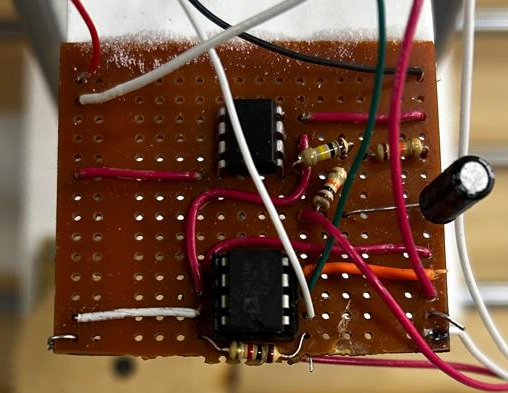
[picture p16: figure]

Hardware Setup
Preconditions | - Sistema energizado con 12v - Circuito amplificación - Celda de carga - Sistema en correcto funcionamiento
Test Procedure (numbered steps) | 1. Se realizo el circuito de amplificación de la señal de la celda de carga 2. Se hicieron pruebas por medio de un multímetro para saber cuánto voltaje estaba asociado a cada peso 3. Se realizo una caracterización de la celda de carga para luego enviarla y leerla en VsCode 4. Se realizo el código correspondiente para hacer lectura y impresión de los datos.
Expected Results | Actual Results
Al colocar cargas con pesos específicos el sistema debe representar los respectivos valores, si el rango esta sobre el establecido debe mostrar por medio de UART ERR_WEIGHT_OUT_OF_RANGE. | Con pesos específicos el sistema mostró los valores esperados. Con 1100g el sistema arrojo ERR_WEIGHT_OUT_OF_RANGE.

Evidence

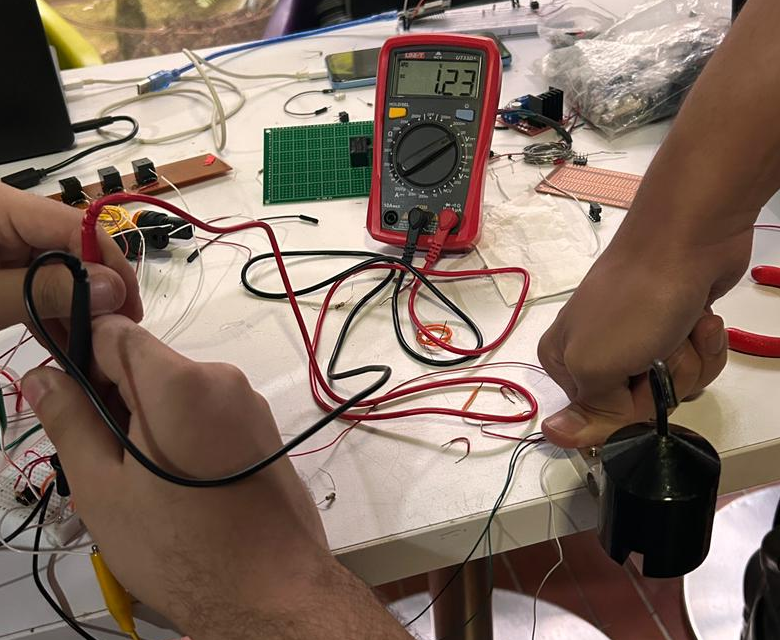
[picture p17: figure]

Executed by / Date | Reviewed by (TL) / Date
Michael Cuello, Carlos Murillo, Owen Montiel | Carlos Murillo

Universidad EIA | Sistemas Embebidos | AS/RS Embedded System

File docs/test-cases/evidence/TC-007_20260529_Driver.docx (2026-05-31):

TEST CASE | ☐ Passed X Failed ☐ Blocked

TC-007
Requirement Traceability | RF-07,RF-09
Test Type (Unit / Driver / Integration / HIL / System) | Driver
Test Objective | Recibir señal de los microswitches para leerlos por medio de la ESP32

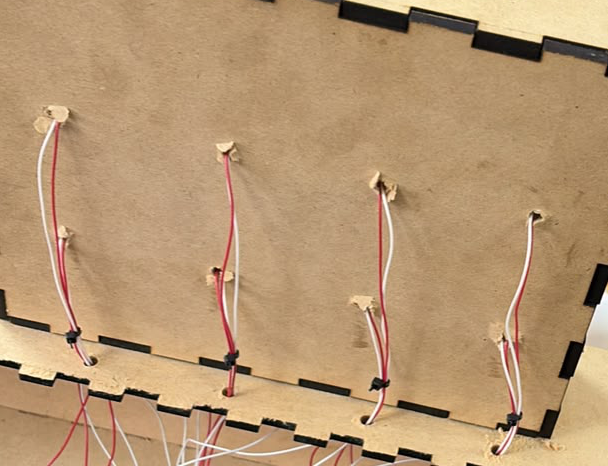
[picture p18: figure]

Hardware Setup
Preconditions | - Circuito de acondicionamiento del senro IR
Test Procedure (numbered steps) | 1. Se realizo el esquemático del circuito 2. Se conectaron los componentes 3. Se soldaron
Expected Results | Actual Results
Al colocar una caja sobre un microswitch este debe mandar una señal de voltaje a la ESP32 | No se logro recibir una señal del microswitch por problemas de conexión

Evidence


Executed by / Date | Reviewed by (TL) / Date
Michael Cuello, Mateo Aldana, Carlos Murillo | Carlos Murillo

Universidad EIA | Sistemas Embebidos | AS/RS Embedded System

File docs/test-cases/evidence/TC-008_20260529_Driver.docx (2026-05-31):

TEST CASE | ☐ Passed X Failed ☐ Blocked

TC-008
Requirement Traceability | RF-12
Test Type (Unit / Driver / Integration / HIL / System) | Driver
Test Objective | Ver el encendido de las luces pilotos por medio de relés


Hardware Setup
Preconditions | - Circuito de acondicionamiento de las luces - Fuente de voltaje - Luces
Test Procedure (numbered steps) | 1. Se realizo el esquemático del circuito 2. Se conectaron los componentes 3. Se soldaron 4. Se hizo la respectiva prueba
Expected Results | Actual Results
Al energizar el relé las luces piloto debían prender solo cambiando la compuerta | Se lograron encender las 3 luces pilotos haciendo el respectivo cambio de las compuertas

Evidence


Executed by / Date | Reviewed by (TL) / Date
Michael Cuello, Mateo Aldana, Carlos Murillo | Carlos Murillo

Universidad EIA | Sistemas Embebidos | AS/RS Embedded System

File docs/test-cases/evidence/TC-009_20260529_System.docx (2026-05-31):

TEST CASE | X Passed ☐ Failed ☐ Blocked

TC-009
Requirement Traceability | RF-13
Test Type (Unit / Driver / Integration / HIL / System) | System
Test Objective | Ver la interfaz grafica y su correcto funcionamiento
Hardware Setup
Preconditions | - Arquitectura por capas - Código interfaz
Test Procedure (numbered steps) | 1. Se realizo el respectivo código para la interfaz
Expected Results | Actual Results
Ver las celdas vacías y llenas de nuestra interfaz, y además poder seleccionar una para enviar nuestra caja | Se obtuvo una interfaz completamente interactiva para el usuario

Evidence

a


Executed by / Date | Reviewed by (TL) / Date
Owen Montiel | Carlos Murillo

Universidad EIA | Sistemas Embebidos | AS/RS Embedded System

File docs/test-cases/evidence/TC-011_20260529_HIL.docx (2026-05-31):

TEST CASE | X Passed ☐ Failed ☐ Blocked

TC-011
Requirement Traceability | RNF-02
Test Type (Unit / Driver / Integration / HIL / System) | HIL
Test Objective | Elaborar la alimentación de todo el circuito y verificar el verdadero funcionamiento


Hardware Setup
Preconditions | - Fuente 12v -Transformador -Conversor de 5v
Test Procedure (numbered steps) | 1. Se realizo el circuito de acondicionamiento de fuente 2. Se realizaron los respectivos puntos de soldadura.
Expected Results | Actual Results
Recibir 12v y 5v del circuito de acondicionamiento de alimentación | Se obtuvieron todos los resultados deseados.

Evidence


Executed by / Date | Reviewed by (TL) / Date
Michael Cuello, Mateo Aldana, Carlos Murillo | Carlos Murillo

Universidad EIA | Sistemas Embebidos | AS/RS Embedded System

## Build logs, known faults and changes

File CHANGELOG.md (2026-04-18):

# Changelog — AS/RS Embedded System

## [Entrega 1] - 2026-03-11

### Agregado
- README.md con definición del problema, roles, alcance y objetivos.

## [Entrega 2] - 2026-03-27

### Agregado
- SRS con 13 requisitos funcionales y 6 no funcionales.
- Plan de testing por 5 niveles.
- SRTM inicial con 19 requisitos mapeados.

## [Entrega 3] - 2026-04-17

### Agregado
- (Actualizar con lo entregado)

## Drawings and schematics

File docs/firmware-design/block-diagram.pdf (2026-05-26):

## AS/RS Embedded System — Diagrama de bloques

### Fuente 12V / 5A

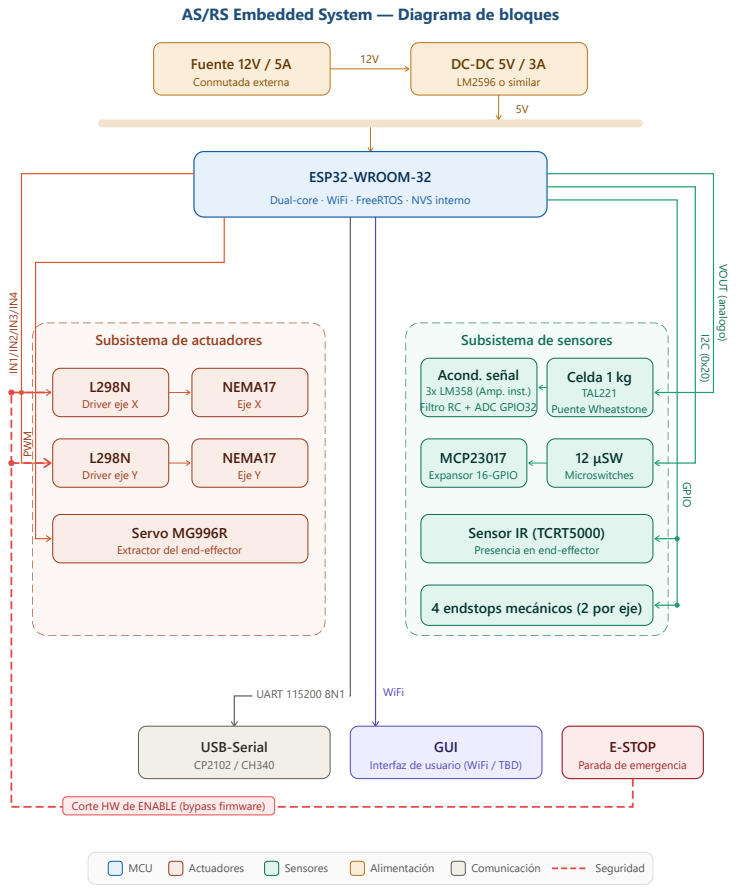
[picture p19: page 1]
Conmutada externa; DC-DC 5V / 3A LM2596 o similar; L298N Driver eje X; NEMA17 Eje X; L298N Driver eje Y; NEMA17 Eje Y; Celda 1 kg TAL221 Puente Wheatstone; MCP23017 Expansor 16-GPIO; 12 μSW Microswitches; PWM; VOUT (analogo); GPIO; UART 115200 8N1; WiFi; USB-Serial CP2102 / CH340; GUI; MCU; Actuadores; Sensores; Alimentación; Comunicación; Seguridad

ESP32-WROOM-32
Dual-core · WiFi · FreeRTOS · NVS interno

Subsistema de actuadores

Subsistema de sensores
Acond. señal
3x LM358 (Amp. inst.)
Filtro RC + ADC GPIO32

Servo MG996R
Extractor del end-effector

Sensor IR (TCRT5000)
Presencia en end-effector

4 endstops mecánicos (2 por eje)

E-STOP
Parada de emergencia

Interfaz de usuario (WiFi / TBD)

Corte HW de ENABLE (bypass firmware)

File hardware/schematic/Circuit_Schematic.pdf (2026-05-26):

Celdu | Je | Caryn | Su
! | ↑ 2

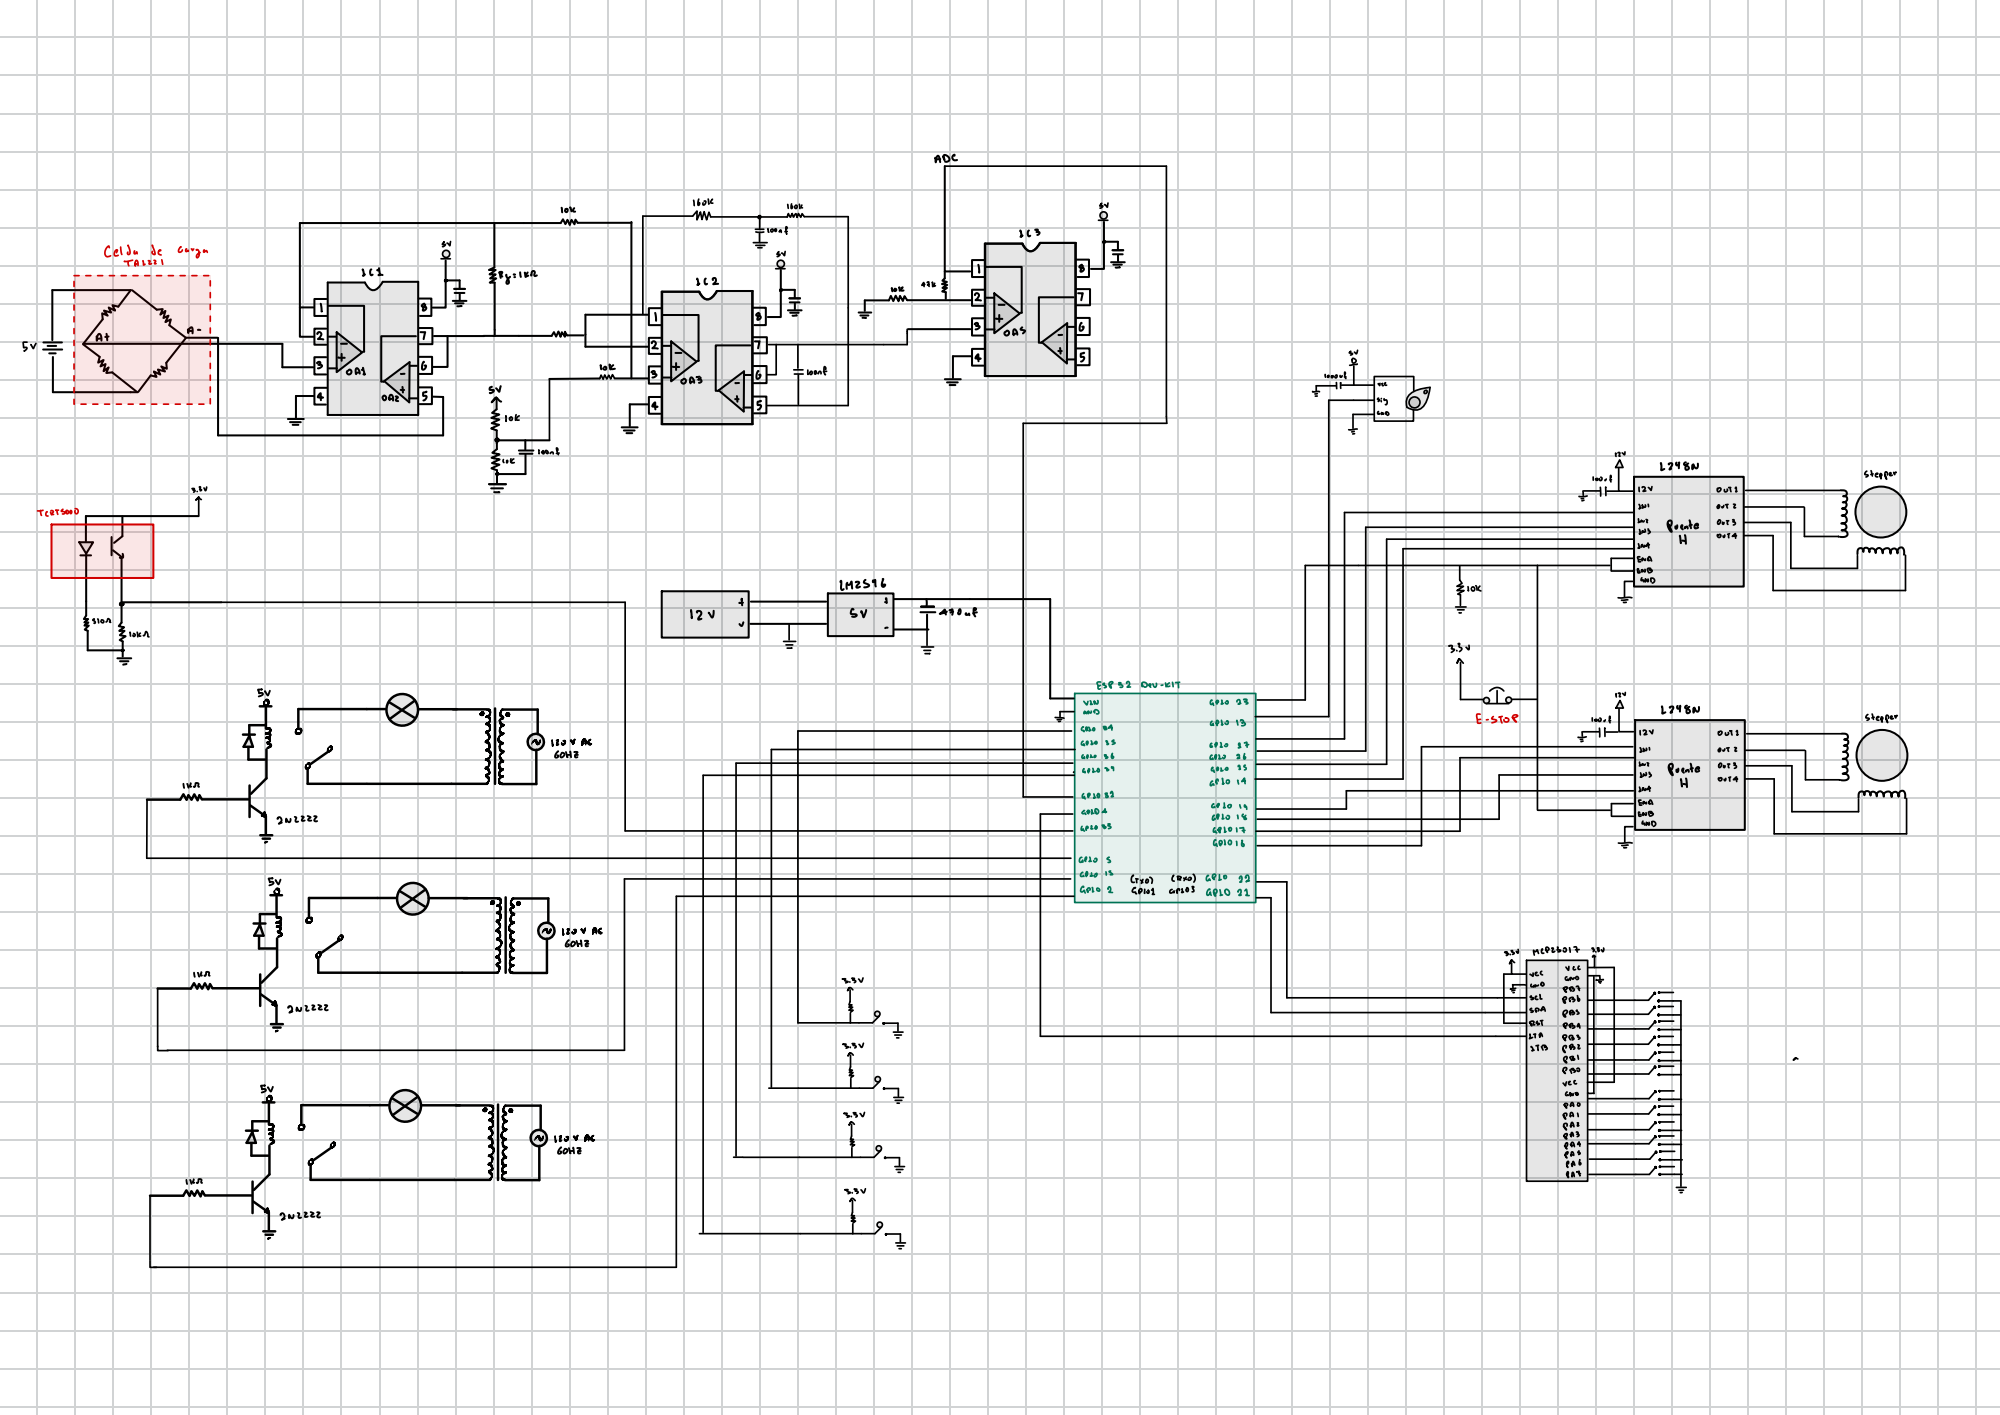
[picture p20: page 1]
ADC; TAL221; oas; -ori.; 1000 of loonf G; oas -; TCRTS000; 12 v slor; ESP32; Dev-KIT; VIN; anco 23; anD; E STOP; omm; Gooa; (RXo) GPLO; Gro2; <Pol; arcos; apLo el; MCP23017

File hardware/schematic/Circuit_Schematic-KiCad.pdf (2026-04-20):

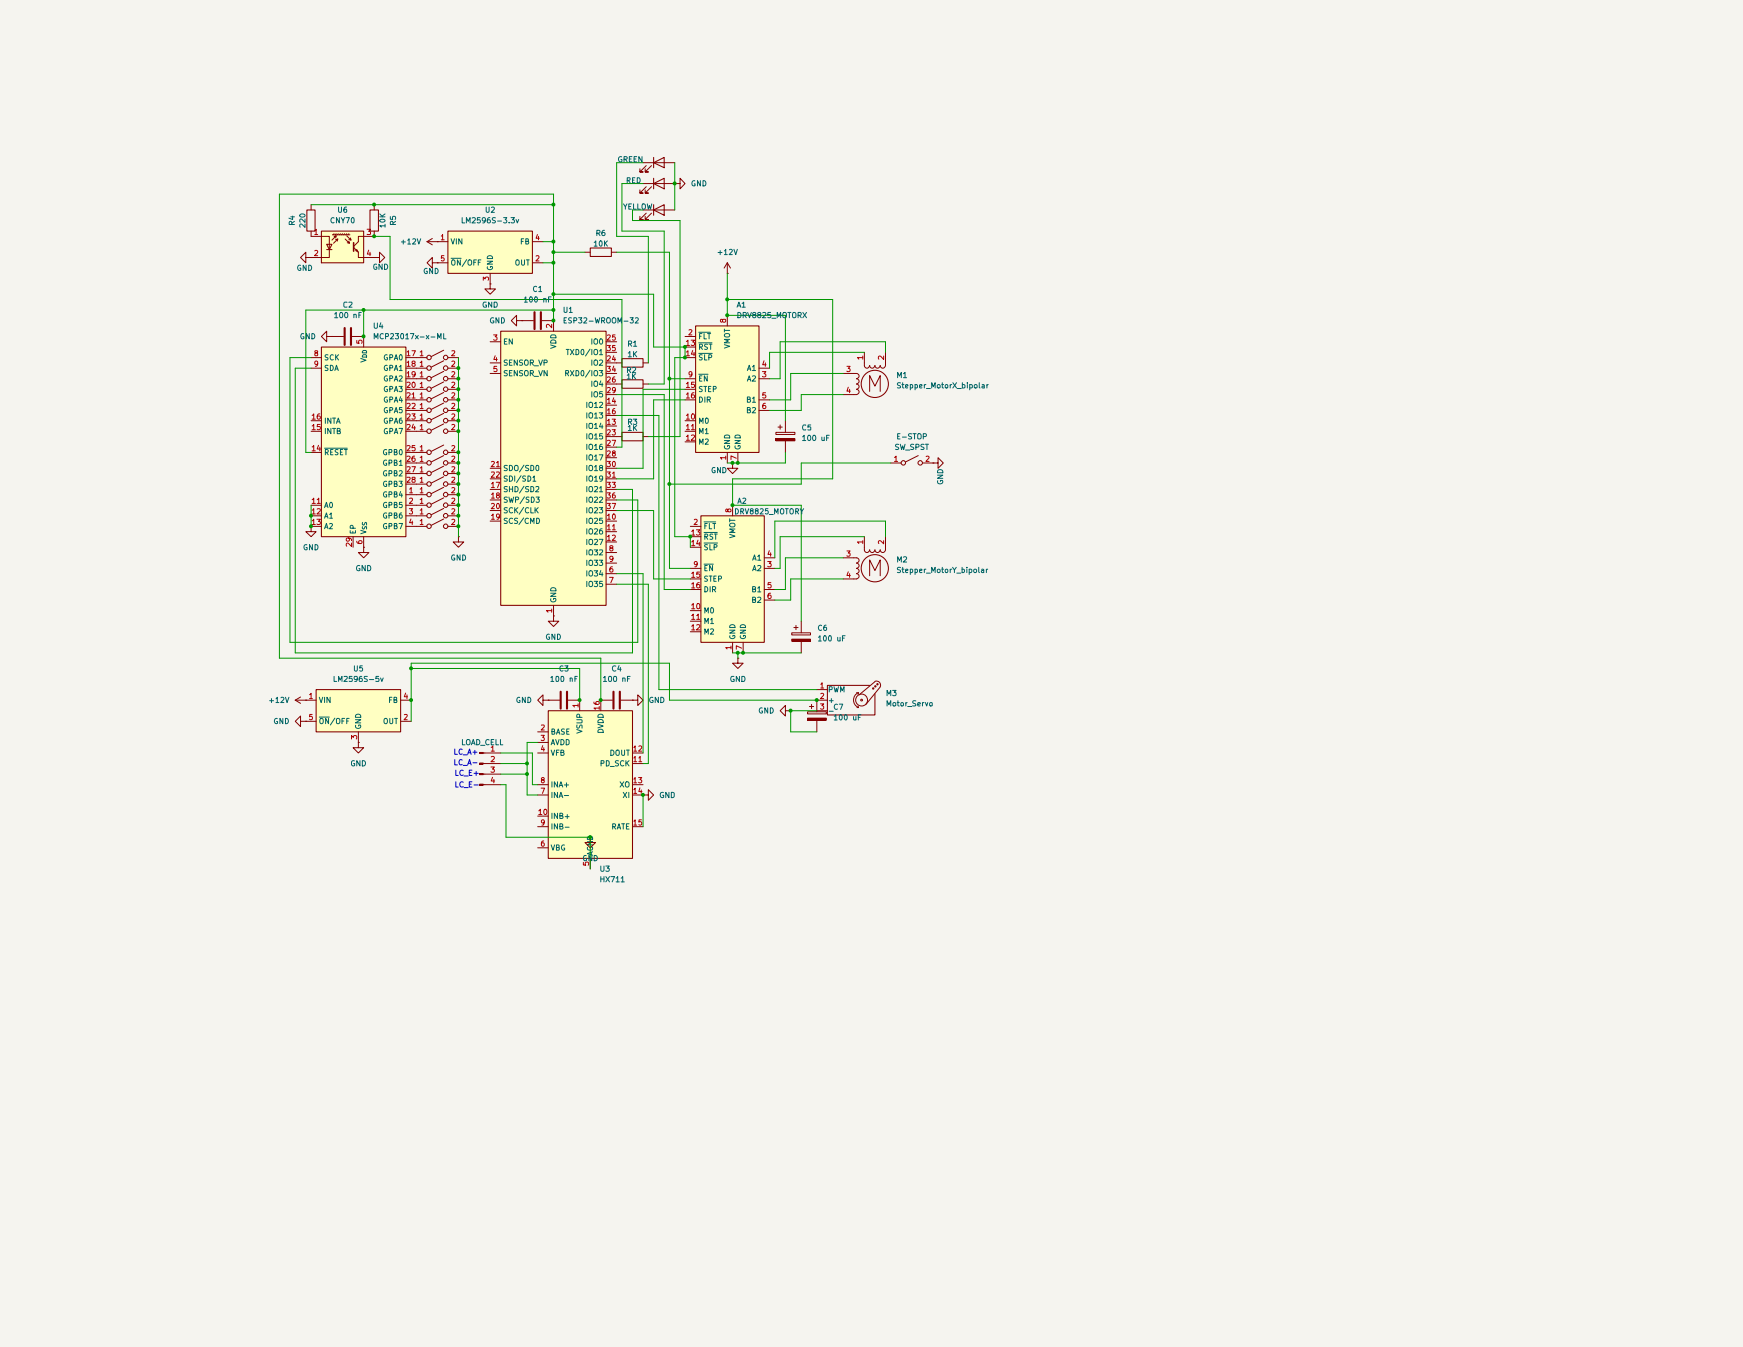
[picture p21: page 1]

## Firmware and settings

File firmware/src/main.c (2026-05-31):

#include <stdio.h>
#include "freertos/FreeRTOS.h"
#include "freertos/task.h"
#include "app/logger.h"
#include "app/system.h"
 
void app_main(void)
{
    // Logger primero — antes de cualquier otra cosa
    logger_init();
 
    // Pequeña pausa para que el logger arranque su tarea
    vTaskDelay(pdMS_TO_TICKS(100));
 
    LOG_I("BOOT", ERR_OK, "app_main iniciando");
 
    // Lanzar la maquina de estados
    system_init();
 
    // app_main NO debe retornar — si retorna, FreeRTOS mata las tareas
    // Mantenerlo vivo con un loop
    while (1) {
        vTaskDelay(pdMS_TO_TICKS(10000));
    }
}

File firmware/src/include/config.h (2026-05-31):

#pragma once

// =============================================================================
// config.h — Configuración global del sistema AS/RS
// Editar este archivo para ajustar pines y parámetros del sistema
// =============================================================================

// --- Firmware ---
#define FIRMWARE_VERSION     "v1.0.0"

// --- UART GUI ---
#define UART_GUI_PORT        UART_NUM_0
#define UART_GUI_BAUDRATE    115200
#define UART_GUI_TX          GPIO_NUM_1
#define UART_GUI_RX          GPIO_NUM_3

// Stepper X (L298N #1)
#define STEPPER_X_IN1        GPIO_NUM_16
#define STEPPER_X_IN2        GPIO_NUM_17
#define STEPPER_X_IN3        GPIO_NUM_18
#define STEPPER_X_IN4        GPIO_NUM_19

// Stepper Y (L298N #2)
#define STEPPER_Y_IN1        GPIO_NUM_25
#define STEPPER_Y_IN2        GPIO_NUM_26
#define STEPPER_Y_IN3        GPIO_NUM_27
#define STEPPER_Y_IN4        GPIO_NUM_14

// Servo SG-5010
#define SERVO_GPIO           GPIO_NUM_13
#define SERVO_PWM_CHANNEL    0
#define SERVO_FREQ_HZ        50
#define SERVO_MIN_US         500
#define SERVO_MAX_US         2500
#define SERVO_RETRACTED_DEG  0
#define SERVO_EXTENDED_DEG   90

// Celda de carga
#define LOAD_CELL_ADC_CH     ADC1_CHANNEL_4   // GPIO 32
#define LOAD_CELL_SAMPLES    64
#define LOAD_CELL_FILTER     10
#define WEIGHT_MIN_G         10.0f
#define WEIGHT_MAX_G         1000.0f

// UART switches (ESP32 secundaria)
#define UART_SW_PORT         UART_NUM_1
#define UART_SW_BAUDRATE     115200
#define UART_SW_RX           GPIO_NUM_21   // recibe datos de la ESP32 secundaria
#define UART_SW_TX           GPIO_NUM_22   // por si necesitamos enviar comandos a la secundaria (opcional)

// Endstops
#define ENDSTOP_X_HOME       GPIO_NUM_34
#define ENDSTOP_X_LIMIT      GPIO_NUM_35
#define ENDSTOP_Y_HOME       GPIO_NUM_36
#define ENDSTOP_Y_LIMIT      GPIO_NUM_39

// Sensor IR
#define IR_SENSOR_GPIO       GPIO_NUM_33

// E-Stop
#define ESTOP_GPIO           GPIO_NUM_23

// Luces piloto (relés)
#define LIGHT_RED_GPIO       GPIO_NUM_2
#define LIGHT_GREEN_GPIO     GPIO_NUM_5
#define LIGHT_YELLOW_GPIO    GPIO_NUM_15

// Matriz
#define MATRIX_COLS          4
#define MATRIX_ROWS          3

// Pasos por celda 
#define STEPS_PER_CELL_X     200
#define STEPS_PER_CELL_Y     200

// FreeRTOS stacks y prioridades
#define STACK_SIZE_MOTION    4096
#define STACK_SIZE_GUICOMM   4096
#define STACK_SIZE_INVENTORY 2048
#define STACK_SIZE_LOGGER    4096

#define PRIORITY_MOTION      5
#define PRIORITY_SAFETY      6
#define PRIORITY_GUICOMM     3
#define PRIORITY_INVENTORY   3
#define PRIORITY_LOGGER      2

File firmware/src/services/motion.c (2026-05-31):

#include <stdbool.h>
#include "freertos/FreeRTOS.h"
#include "freertos/task.h"
#include "driver/gpio.h"
#include "motion.h"
#include "../drivers/stepper.h"
#include "../include/config.h"
#include "../app/logger.h"

// --------------------------------------------------------------------------
// Parámetros de movimiento
// Ajustar STEP_DELAY_US según velocidad real del motor en el prototipo.
// --------------------------------------------------------------------------
#define STEP_DELAY_US        2000    // 2 ms por paso → ~500 pasos/s
#define HOMING_STEP_DELAY_US 3000    // más lento durante homing (más torque, más seguro)

// Máximo de pasos permitidos durante homing antes de declarar fallo.
// Con STEPS_PER_CELL=200 y 4 columnas, el recorrido máximo es ~800 pasos.
// Se permite 2× de margen para cubrir variaciones mecánicas.
#define HOMING_MAX_STEPS_X   (MATRIX_COLS * STEPS_PER_CELL_X * 2)
#define HOMING_MAX_STEPS_Y   (MATRIX_ROWS * STEPS_PER_CELL_Y * 2)

// Timeout por movimiento a celda: pasos máximos * tiempo por paso * 2 de margen
// Expresado en ticks de FreeRTOS para comparar con xTaskGetTickCount()
#define MOVE_TIMEOUT_MS      15000   // 15 s — cubre A→D o 1→3 con margen

// --------------------------------------------------------------------------
// Estado interno del módulo
// --------------------------------------------------------------------------
static uint8_t current_col = 0;
static uint8_t current_row = 0;
static bool    homed        = false;

// --------------------------------------------------------------------------
// Helpers de endstop
// --------------------------------------------------------------------------

/** Configura los 4 endstops como entradas con pull-up (activos en bajo). */
static void init_endstops(void)
{
    const gpio_num_t pins[] = {
        ENDSTOP_X_HOME, ENDSTOP_X_LIMIT,
        ENDSTOP_Y_HOME, ENDSTOP_Y_LIMIT,
    };
    for (int i = 0; i < 4; i++) {
        gpio_config_t cfg = {
            .pin_bit_mask = (1ULL << pins[i]),
            .mode         = GPIO_MODE_INPUT,
            .pull_up_en   = GPIO_PULLUP_DISABLE,
            .pull_down_en = GPIO_PULLDOWN_DISABLE,
            .intr_type    = GPIO_INTR_DISABLE,
        };
        gpio_config(&cfg);
    }
}

/** Retorna true si el endstop indicado está activado (nivel LOW). */
static inline bool endstop_triggered(gpio_num_t pin)
{
    return gpio_get_level(pin) == 0;
}

// --------------------------------------------------------------------------
// Homing de un eje
//
// Mueve el stepper en DIR_BACKWARD (hacia home) paso a paso.
// Se detiene cuando el endstop se activa o se alcanza max_steps.
// --------------------------------------------------------------------------
static asrs_err_t home_axis(stepper_id_t motor,
                             gpio_num_t   endstop_pin,
                             int          max_steps,
                             const char  *axis_name)
{
    char msg[48];

    snprintf(msg, sizeof(msg), "homing %s...", axis_name);
    LOG_I("MOTION", ERR_OK, msg);

    for (int i = 0; i < max_steps; i++) {
        if (endstop_triggered(endstop_pin)) {
            snprintf(msg, sizeof(msg), "%s home OK en %d pasos", axis_name, i);
            LOG_I("MOTION", ERR_OK, msg);
            return ERR_OK;
        }
        stepper_move(motor, 1, DIR_BACKWARD, HOMING_STEP_DELAY_US);
    }

    // Llegamos al límite de pasos sin encontrar el endstop
    snprintf(msg, sizeof(msg), "%s endstop no detectado en %d pasos", axis_name, max_steps);
    LOG_E("MOTION", ERR_STEPPER_ENDSTOP_MISSING, msg);
    return ERR_STEPPER_ENDSTOP_MISSING;
}

// --------------------------------------------------------------------------
// API pública
// --------------------------------------------------------------------------

void motion_init(void)
{
    init_endstops();
    homed       = false;
    current_col = 0;
    current_row = 0;
    LOG_I("MOTION", ERR_OK, "Motion inicializado");
}

asrs_err_t motion_home(void)
{
    asrs_err_t err;

    // Primero eje X, luego eje Y — orden importante para evitar colisiones
    err = home_axis(STEPPER_X, ENDSTOP_X_HOME, HOMING_MAX_STEPS_X, "X");
    if (err != ERR_OK) return err;

    err = home_axis(STEPPER_Y, ENDSTOP_Y_HOME, HOMING_MAX_STEPS_Y, "Y");
    if (err != ERR_OK) return err;

    current_col = 0;
    current_row = 0;
    homed       = true;

    LOG_I("MOTION", ERR_OK, "Homing completado. Posicion=(0,0)");
    return ERR_OK;
}

asrs_err_t motion_goto_cell(uint8_t col, uint8_t row)
{
    if (col >= MATRIX_COLS || row >= MATRIX_ROWS) {
        char msg[48];
        snprintf(msg, sizeof(msg), "celda fuera de rango col=%d row=%d", col, row);
        LOG_E("MOTION", ERR_STEPPER_OUT_OF_BOUNDS, msg);
        return ERR_STEPPER_OUT_OF_BOUNDS;
    }

    // Calcular delta de pasos
    int delta_x = (int)col - (int)current_col;
    int delta_y = (int)row - (int)current_row;

    char msg[64];
    snprintf(msg, sizeof(msg), "goto col=%d row=%d dx=%d dy=%d",
             col, row, delta_x, delta_y);
    LOG_I("MOTION", ERR_OK, msg);

    // Mover X primero, luego Y — evita movimientos diagonales sin control
    if (delta_x != 0) {
        stepper_dir_t dir = (delta_x > 0) ? DIR_FORWARD : DIR_BACKWARD;
        int steps = (delta_x > 0) ? delta_x : -delta_x;
        stepper_move(STEPPER_X, steps * STEPS_PER_CELL_X, dir, STEP_DELAY_US);
    }

    if (delta_y != 0) {
        stepper_dir_t dir = (delta_y > 0) ? DIR_FORWARD : DIR_BACKWARD;
        int steps = (delta_y > 0) ? delta_y : -delta_y;
        stepper_move(STEPPER_Y, steps * STEPS_PER_CELL_Y, dir, STEP_DELAY_US);
    }

    current_col = col;
    current_row = row;

    snprintf(msg, sizeof(msg), "posicion actualizada col=%d row=%d", col, row);
    LOG_I("MOTION", ERR_OK, msg);
    return ERR_OK;
}

void motion_get_position(uint8_t *col_out, uint8_t *row_out)
{
    if (col_out) *col_out = current_col;
    if (row_out) *row_out = current_row;
}

bool motion_is_homed(void)
{
    return homed;
}

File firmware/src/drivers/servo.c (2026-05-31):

#include "driver/ledc.h"
#include "servo.h"
#include "../include/config.h"
#include "../app/logger.h"

#define LEDC_TIMER      LEDC_TIMER_0
#define LEDC_MODE       LEDC_LOW_SPEED_MODE
#define LEDC_RESOLUTION LEDC_TIMER_13_BIT
#define LEDC_MAX_DUTY   8191

static uint32_t angle_to_duty(uint8_t degrees) {
    uint32_t us = SERVO_MIN_US + ((uint32_t)degrees * (SERVO_MAX_US - SERVO_MIN_US)) / 180;
    return (us * LEDC_MAX_DUTY) / 20000;
}

void servo_init(void) {
    ledc_timer_config_t timer = {
        .speed_mode      = LEDC_MODE,
        .timer_num       = LEDC_TIMER,
        .duty_resolution = LEDC_RESOLUTION,
        .freq_hz         = SERVO_FREQ_HZ,
        .clk_cfg         = LEDC_AUTO_CLK,
    };
    ledc_timer_config(&timer);

    ledc_channel_config_t channel = {
        .speed_mode = LEDC_MODE,
        .channel    = SERVO_PWM_CHANNEL,
        .timer_sel  = LEDC_TIMER,
        .intr_type  = LEDC_INTR_DISABLE,
        .gpio_num   = SERVO_GPIO,
        .duty       = angle_to_duty(SERVO_RETRACTED_DEG),
        .hpoint     = 0,
    };
    ledc_channel_config(&channel);
    LOG_I("SERVO", ERR_OK, "Servo inicializado");
}

asrs_err_t servo_set_angle(uint8_t degrees) {
    if (degrees > 180) {
        LOG_E("SERVO", ERR_SERVO_INIT, "Angulo fuera de rango");
        return ERR_SERVO_INIT;
    }
    ledc_set_duty(LEDC_MODE, SERVO_PWM_CHANNEL, angle_to_duty(degrees));
    ledc_update_duty(LEDC_MODE, SERVO_PWM_CHANNEL);
    return ERR_OK;
}

asrs_err_t servo_extend(void) {
    LOG_I("SERVO", ERR_OK, "Extendiendo");
    return servo_set_angle(SERVO_EXTENDED_DEG);
}

asrs_err_t servo_retract(void) {
    LOG_I("SERVO", ERR_OK, "Retrayendo");
    return servo_set_angle(SERVO_RETRACTED_DEG);
}

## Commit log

2026-04-18 docs(testing): agregar plantilla de test case
2026-04-18 docs(design): agregar diagrama de bloques del sistema
2026-04-18 docs(design): agregar diagrama de bloques corregido
2026-04-18 docs: Bill of Materials de componentes electronicos
2026-04-20 hw(schematic): agregar proyecto KiCad del esquemático
    [EquematicoElectronico_S.E.kicad_pcb, EquematicoElectronico_S.E.kicad_sch]
2026-04-20 hw(schematic): agregar PDF exportado del esquemático
2026-04-20 docs(design): correccion en diagrama de bloques (acondicionamiento de señal)
2026-04-20 docs(BOM): Revision de Bill of Materials de componentes electronicos
2026-05-25 hw(bom): agregar lista de componentes en PDF y CSV
    [BOM-ASRS.xlsx]
2026-05-25 hw(bom): actualizar lista de componentes en PDF y CSV
    [BOM-ASRS.xlsx]
2026-05-25 hw(cad): agregar renders CAD y fotos de piezas impresas
2026-05-25 docs(srs): actualizar SRS a versión 1.2
    [Schematic-Signal_Conditioning.kicad_pcb, Schematic-Signal_Conditioning.kicad_sch]
2026-05-26 hw(BOM): actualizar lista de componentes
    [BOM-ASRS.xlsx]
2026-05-26 hw(schematic): agregar esquemático detallado del circuito
2026-05-26 docs(design): actualizar diagrama de bloques
2026-05-29 Add hardware prototype photo
2026-05-29 Upload photo of universal PCB for signal processing
2026-05-29 hw(photos): Borrar imagen pcb procesamiento señal celda
2026-05-29 hw(photos): Upload photo of microswitch matrix assembly
2026-05-31 feat(drivers): agregar drivers de load_cell, servo, stepper y switch_uart
2026-05-31 feat(app): agregar módulos de gui_comm, logger y system
2026-05-31 test(TC-001): Homing al boot
2026-05-31 test(TC-004): Parada de emergencia E-Stop
2026-05-31 test(TC-005): Sensor IR TCRT5000
2026-05-31 test(TC-006): Medición de peso AD623
2026-05-31 test(TC-013): Implementación física PCB
2026-06-01 hw(pcb): agregar imagen de la PCB del acondicionamiento de señal de la celda de carga
2026-06-01 hw(pcb): añadir diseño de la PCB para el sensor IR
2026-06-01 hw(pcb): añadir PCB de control de LEDs mediante relés
2026-06-01 hw(assembly): agregar montaje de indicadores y botón de parada
2026-06-01 hw(photos): agregar montaje del sistema de transmisión del eje y
2026-06-01 hw(photos): agregar montaje del sistema de transmisión del eje x
2026-06-01 hw(photos): agregar montaje del sistema de transmisión por cremallera del eje Z
